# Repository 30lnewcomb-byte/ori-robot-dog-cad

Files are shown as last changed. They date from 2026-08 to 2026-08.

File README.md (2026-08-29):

# Ori Robot Dog CAD

This repository is the **mechanical/CAD workspace** for Ori Robot Dog.

## Source of truth

The authoritative design is the parametric Python/CadQuery source plus the master parameter system:

- `Source/Parameters/master_parameters.py` — dimensional and hardware source of truth.
- `Source/CAD/` — parametric part and assembly generators.
- `CAD_STEP/` — tracked high-fidelity STEP deliverables.
- `CAD_STL/` — tracked print-ready STL deliverables.
- `OpenSCAD/` — simplified, text-readable preview/reference models only.
- `Validation_and_Docs/` — validators, analyses, BOM, handoff, and engineering records.
- `ENGINEERING_RULES.md` — quality rules for AI-assisted mechanical work.

Generated STEP/STL files are deliverables, not editable design authority. Regenerate them from source after changing the parametric CAD.

## Current implementation state

The repository currently generates:

- 4 mirrored instances of one master leg architecture.
- **2 actuated joints per leg**: hip pitch + knee.
- **8 implemented leg DOF** total.
- A **6-DOF arm** with the grip actuator kept in the wrist/forearm and a passive interchangeable gripper.
- A **2-DOF head**: pan about Z and pitch about Y.
- **16 implemented actuated DOF** total (8 legs + 6 arm + 2 head).

The project also carries a **20-DOF target architecture** (12 leg + 6 arm + 2 head). The additional four hip-yaw joints are specified in the software handoff but are **not implemented in the current leg CAD**. See `Validation_and_Docs/Documentation/KNOWN_BLOCKERS.md`.

## One-command validation

From the repository root:

```text
python validate.py
```

This runs the static repository audit and the geometry/engineering validation suite. GitHub Actions runs the same validation plus a separate CadQuery smoke build.

A successful validation run proves only what the automated checks actually test. It does **not** prove physical fit, print success, FDM layer strength, dynamic behavior, servo performance under load, or long-term gear wear.

## CAD quality standard

Read `ENGINEERING_RULES.md` before changing mechanical source.

The core rule is simple:

> **AI-generated CAD is not considered correct because it looks good. The person making the CAD owns the reasonable verification work.**

Meaningful changes should be checked against geometry, hardware interfaces, assembly, motion and clearance, printability, structural assumptions, mass effects, and downstream dependencies.

## Known engineering blockers

- Hip-yaw is a target feature but not yet implemented in the CAD.
- Raspberry Pi 3 vs Pi 4 remains unresolved for the final electronics packaging.
- The upper-link crash-case reinforcement decision remains intentionally deferred.
- No physical assembly/printing validation has been performed yet.
- Gear backlash/wear, heat-set insert pull-out, seam strength, dynamic loads, and FDM anisotropy remain physical-validation tasks.

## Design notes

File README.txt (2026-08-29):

ORI ROBOT DOG — CAD REPOSITORY
==============================

This repository is the mechanical/CAD workspace for Ori Robot Dog.

SOURCE OF TRUTH
  Source/Parameters/master_parameters.py   Master parameters for generated CAD.
  Source/CAD/                              Parametric Python/CadQuery generators.
  CAD_STEP/                               Authoritative high-fidelity STEP deliverables.
  CAD_STL/                                Print-ready STL deliverables.
  OpenSCAD/                               Simplified text-readable previews only.
  Validation_and_Docs/                    Validation, engineering analysis, BOM, and handoff.

IMPORTANT: STEP/STL exports are deliverables, not the design source. Regenerate them from
parametric source after a design change.

CURRENT CAD STATE
  Robot envelope: validated by the current assembly build (exact dimensions are reported by
                  the validation suite rather than copied here).
  Leg architecture currently generated: 2 actuated joints per leg (hip pitch + knee).
  Arm: 6-DOF with servo-in-wrist passive gripper.
  Head: 2-DOF pan + pitch.
  Current generated actuated DOF: 16 (8 legs + 6 arm + 2 head).
  Target architecture: 20 DOF (12 leg + 6 arm + 2 head).

The four hip-yaw joints exist in the software target map but are NOT implemented in the current
leg CAD. See Validation_and_Docs/Documentation/KNOWN_BLOCKERS.md before treating those joints as real.

ENGINEERING RULES
  Read ENGINEERING_RULES.md. AI-generated geometry is not accepted by appearance alone.
  Meaningful changes must be checked for geometry, interfaces, assembly, motion, manufacturability,
  structural assumptions, mass effects, and downstream breakage.

VALIDATION
  GitHub Actions runs the static repository audit, CadQuery smoke build, leg validation, robot
  validation, wrist validation, load analysis, shaft analysis, and arm/wrist load analysis.
  These are CAD/calculation checks only; no physical printing or hardware validation is implied.

UNRESOLVED ENGINEERING ITEMS
  - Implement or deliberately remove/freeze the four hip-yaw joints.
  - Pi 3 vs Pi 4 controller selection still affects electronics packaging.
  - Upper-link crash-case reinforcement remains intentionally deferred pending physical evidence.
  - Physical fit, backlash/wear, insert pull-out, seam strength, dynamics, and FDM anisotropy remain
    unverified.

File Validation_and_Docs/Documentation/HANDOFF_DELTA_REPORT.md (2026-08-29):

# Ori Mechanical Handoff — Delta / Cleanup Record

**Date of this cleanup:** 2026-08-29

This record supersedes stale path/state claims in the older 2026-08-25 handoff delta. Changes below are repository-maintenance and correctness work; they do not imply physical validation.

## What was corrected

- Added `ENGINEERING_RULES.md` to make AI-generated CAD verification requirements explicit.
- Added a standard GitHub Actions CAD validation workflow.
- Added `validate.py` as the single local validation entry point.
- Fixed repository-root resolution in `Source/CAD/Master/build_common.py`.
- Canonicalized generated STEP/STL output to top-level `CAD_STEP/` and `CAD_STL/` deliverable folders.
- Fixed validation scripts that still assumed the old pre-`Source/` directory layout.
- Reworked the full-robot validator so it does not contain always-true checks and reports the actual current 16-DOF implementation state.
- Reworked wrist validation so it does not claim powered/unpowered behavior that has not been physically tested.
- Corrected the wrist grip servo/gear coordinate system: the grip servo shaft and spur gear are now both along +X, and the passive tool gear is aligned to the same wrist plane.
- Updated the software joint map to distinguish implemented joints from target-only hip-yaw joints and corrected head pan/pitch axes.
- Updated BOM and documentation to distinguish current hardware from target hardware.
- Corrected the arm analysis record's PETG density-unit error.
- Reworked FEA source paths so the optional structural analysis uses the current repository layout.

## Current engineering state

- Current generated leg architecture: 2 actuated joints per leg (hip pitch + knee) = 8 leg DOF.
- Current arm: 6 DOF.
- Current head: 2 DOF.
- Current generated actuated DOF: **16**.
- Target architecture: **20 DOF**, requiring four hip-yaw mechanisms that are not yet in the CAD.

## Validation status

GitHub Actions has successfully completed the CadQuery smoke build on the corrected validation pipeline. The latest pipeline is now configured to continue through the full validation suite after the smoke build.

The checks remain CAD/calculation checks only. They do not replace physical print, fit, strength, dynamic, or hardware tests.

## Remaining blockers

1. Decide whether to implement the four hip-yaw mechanisms or intentionally freeze the 8-DOF leg architecture.
2. Resolve Pi 3 vs Pi 4 for final electronics packaging.
3. Perform physical print and assembly validation.
4. Validate grip backlash/wear, insert pull-out, seam strength, dynamic loads, and FDM anisotropy.
5. Revisit the upper-link crash-case reinforcement only when the decision is supported by testing or better structural analysis.

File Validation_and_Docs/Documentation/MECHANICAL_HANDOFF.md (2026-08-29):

# Ori Robot Dog — Mechanical Handoff

**Status:** CAD/analysis phase. Parametric source builds and automated CAD validation runs in GitHub Actions. No physical printing or hardware validation has been performed.

**CAD system:** Python/CadQuery + `Source/Parameters/master_parameters.py`.
**Primary material:** PETG structure with 626ZZ bearings, 6 mm steel shaft reinforcement, and M3 hardware.
**Printer target:** Bambu Lab A1 Mini, 180 × 180 × 180 mm.

## 1. Current architecture

- 4-legged quadruped generated from one master leg and transformed into FL/FR/RL/RR.
- **Current leg CAD:** 2 actuated joints per leg — hip pitch + knee.
- **Current leg DOF:** 8 total.
- Front 6-DOF arm with the grip actuator retained in the forearm/wrist and a passive interchangeable gripper.
- 2-DOF head: pan about Z and pitch about Y.
- **Current implemented actuated DOF:** 16 (8 leg + 6 arm + 2 head).
- **Target architecture:** 20 DOF (12 leg + 6 arm + 2 head). The four target hip-yaw mechanisms are not implemented in the current CAD.

See `KNOWN_BLOCKERS.md` and `software_handoff_jointmap.json` for the implementation/target distinction.

## 2. Current dimensional model

The master parameter file is authoritative for component dimensions; the assembled robot validator computes the actual current envelope. Do not copy old envelope numbers into new source code.

Current baseline parameters include:

| Quantity | Value |
|---|---:|
| Hip height nominal | 300 mm |
| Upper link | 175 mm |
| Lower link | 175 mm |
| Stance length target | 437 mm |
| Stance width target | 168 mm |
| Torso core | 300 × 150 × 110 mm |
| Head | 90 × 70 × 70 mm |
| A1 Mini build volume | 180³ mm |
| 626ZZ bearing | 6 × 19 × 6 mm |
| HTD-45H body | 51.1 × 20.14 × 40 mm |

Older documents contain alternative envelope numbers. Those are historical unless reproduced by the current validator.

## 3. Actuation and hardware

- HTD-45H baseline: 64 g nominal mass, 6 mm output shaft, 115200 bus, 9–12.6 V parameterized in the master system.
- Current CAD uses 8 leg servos + 6 arm servos + 2 head servos = **16 implemented actuators**.
- BOM includes 12 leg servo purchases because the current leg design needs 8 and retains 4 as spare units.
- 28 × 626ZZ are planned for the current 8 leg + 6 arm bearing-supported joints.
- 10 × 6 mm steel shafts reinforce the hip, knee, shoulder, elbow, and wrist axes.

## 4. Passive gripper

Current `arm.py` implementation uses:

**grip servo in forearm → printed spur gear → coupler gear → eccentric cam → two passive fingers.**

- Standard coupler diameter: 34 mm.
- Retention: 2 × M3 + Ø4 alignment dowel.
- Gear center distance: 18 mm.
- Passive tool contains no servo, motor, battery, or controller.
- Nominal passive gripper mass target: 22 g PETG.

The mechanical architecture is CAD-based and still requires physical gear backlash/wear and grip-force validation.

## 5. Load and structural assessment

The repository contains static load calculations, shaft sizing, and linear-static PETG FEA. These are engineering analyses, not physical certification.

Known result:
- Hip bulkhead FEA is documented as low-stress in the modeled load case.
- Upper-link yoke has a documented high-stress crash-only case. A gusset was deliberately deferred rather than introducing unverified geometry.
- The 500 g arm payload remains an **analysis target**, with printed-link stiffness and physical testing identified as the limiting uncertainties.

## 6. Manufacturing

All current component generators are intended to produce printable parts within the A1 Mini envelope. The repository tracks high-fidelity STEP and print-oriented STL deliverables separately from editable parametric source.

Canonical export helpers now resolve the real repository root and place generated STEP/STL output under `CAD_STEP/` and `CAD_STL/`.

## 7. Serviceability / assembly intent

- Bearings are intended to be replaceable press-fit components.
- 6 mm reinforcement shafts are removable through the joint stacks.
- Torso is split into printable halves with seam alignment and fastener features.
- Battery and electronics have planned service access.
- The gripper uses a removable mechanical coupler so future passive tools can share the same interface.

Actual insertion forces, seam strength, tool access, and final wiring remain physical validation tasks.

## 8. Software handoff

`software_handoff_jointmap.json` is now explicitly versioned as a **current-CAD + target-architecture** handoff:

- `IN_CAD` joints may be used as mechanical facts.
- `NOT_IN_CAD` hip-yaw joints are targets only and must not be driven as though they exist.
- Head axes match the current CAD: pan Z, pitch Y.

Firmware should consume the implementation state rather than assuming the old 20-DOF claim is already physically realized.

## 9. Validation

Use the repository root command:

```text
python validate.py
```

GitHub Actions additionally runs the CadQuery smoke build and the validation suite on pushes to `main` and pull requests.

## 10. Remaining decisions / blockers

- Implement a real four-joint hip-yaw stage, or deliberately freeze the robot as an 8-DOF leg architecture.
- Select Raspberry Pi 3 vs Pi 4 for final electronics packaging.
- Perform physical print/fit validation before calling the design build-ready.
- Validate gear backlash/wear, insert pull-out, seam strength, servo loading, and dynamic behavior.

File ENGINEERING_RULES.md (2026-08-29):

# Ori Engineering Rules

## AI/CAD responsibility

AI-generated CAD is never considered correct merely because it looks good, imports successfully, or passes a superficial check. Before a change is called complete, verify geometry, interfaces, assembly, motion/clearance, manufacturability, and relevant engineering assumptions. If a property cannot be verified, mark it unverified.

The agent making a CAD change is responsible for checking the result. The user should not have to discover mistakes that the agent could reasonably have caught.

## Source of truth

- `Source/CAD/` is the authoritative parametric CAD source.
- `Source/Parameters/master_parameters.py` is the authoritative parameter source.
- `CAD_STEP/` and `CAD_STL/` are deliverables/exports, not editable source.
- `OpenSCAD/` is legacy/reference material unless explicitly promoted.
- `Validation_and_Docs/` records validation, analysis, BOM, and handoff information.

## Mechanical integrity

- Preserve working interfaces unless a deliberate design change requires otherwise.
- Hardware dimensions and axes must come from the authoritative hardware models/parameters.
- A component must be checked in context where its loads, mating parts, motion, and assembly matter.
- Do not claim a target architecture is implemented when the current CAD does not implement it.
- Do not weaken, remove, or rewrite a validator merely to obtain PASS.
- Prefer fixing the design or fixing an objectively incorrect test.

## Arm reinforcement requirement

The arm's metal shaft inserts are structural reinforcement members, not cosmetic or optional hardware. The arm CAD must positively locate and retain them, provide adequate surrounding material, and provide a credible load path through the reinforced joint/link. Any arm change affecting a shaft interface must re-check shaft dimensions, retention, bearing/servo clearance, assembly access, and load-transfer assumptions.

## Validation

A green test is evidence only for what the test actually checks. Keep implementation status, analytical validation, and physical verification distinct.

When changing geometry, run the narrowest relevant validation first, then the complete repository validation before declaring the change complete.

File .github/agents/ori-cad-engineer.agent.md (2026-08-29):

---
name: Ori CAD Engineer
description: Engineering-focused Copilot agent for the Ori Robot Dog CAD repository. Audits, improves, validates, and documents parametric CAD without treating generated geometry as correct by default.
tools:
  - read
  - edit
  - terminal
  - search
---

You are the Ori CAD Engineer. You are a cautious mechanical/CAD engineering agent working on the Ori Robot Dog project.

PRIMARY OBJECTIVE
- Improve the repository so Liam spends less time manually debugging CAD, validation, documentation, exports, and project bookkeeping.
- Make changes that are traceable, testable, maintainable, and consistent with the current parametric CAD source of truth.

HARD ENGINEERING RULE
Never accept AI-generated CAD just because it looks good, generates successfully, exports successfully, or passes a superficial check. Before calling a meaningful CAD change complete, verify geometry, interfaces, assembly, motion/clearance where applicable, manufacturability, and relevant engineering assumptions. If something cannot be verified, explicitly mark it UNVERIFIED instead of presenting it as finished.

CORE BEHAVIOR
1. Inspect before editing. Read the relevant source, parameters, validators, and documentation together.
2. Prefer the canonical parametric CadQuery source and master parameters over generated STEP/STL or simplified reference geometry.
3. Preserve working interfaces unless a deliberate design change requires changing them.
4. Do not silently resurrect obsolete mechanisms or historical designs. Treat stale concepts as historical unless the current source promotes them.
5. Never weaken a validator merely to make CI pass. Fix the test when the test is wrong; fix the CAD when the CAD is wrong.
6. Never claim physical validation, print validation, strength validation, or hardware fit has happened unless the available evidence actually supports that claim.
7. Keep units explicit. Use mm for CAD dimensions unless a file explicitly establishes another unit system.
8. Keep generated deliverables deterministic and separate from editable source code.
9. When a parameter exists in the master parameter system, do not duplicate it as a second independent source of truth without a documented reason.
10. When a change can be checked automatically, add or improve an automated check.

REPOSITORY PRIORITIES
- Master parameters and current CadQuery source: authoritative engineering design.
- Validation scripts: executable claims that must remain honest and meaningful.
- CAD_STEP/CAD_STL: generated manufacturing/handoff outputs, not primary design sources.
- OpenSCAD/reference artifacts: simplified or historical/reference material unless explicitly promoted.
- Documentation must agree with the actual implementation, not an older target architecture.

VALIDATION EXPECTATIONS
- Use the repository's canonical validation entry point before declaring work complete.
- At minimum, run the relevant component validator plus the full validation suite when practical.
- Inspect failures and classify them as: CAD defect, validator defect, documentation mismatch, stale artifact, environment/tooling issue, or legitimately unverified physical requirement.
- Prefer tests that derive expected values from the actual master parameters rather than duplicated constants.
- Include assembly/interface checks where geometry alone could still be misleading.

CHANGE MANAGEMENT
- Make the smallest coherent change that solves the problem, but improve adjacent broken bookkeeping when it directly affects correctness.
- Update documentation when implementation changes.
- If exports are generated from source, regenerate them rather than manually editing the export.
- Do not commit secrets, machine-specific paths, or unrelated generated clutter.

ORI-SPECIFIC ENGINEERING CONTEXT
- Printer target: Bambu Lab A1 Mini, nominal build volume 180 x 180 x 180 mm.
- Primary print material target: PETG unless the current design documentation explicitly says otherwise.
- Core leg hardware includes HTD-45H servos, 626ZZ bearings, and M3-class hardware.
- Current implementation must be distinguished from future target architecture; do not represent unimplemented DOF or hardware as present.
- The robot is a real physical build, so assembly access, serviceability, cable routing, fastening, clearances, and realistic hardware envelopes matter.

WHEN SOMETHING LOOKS SUSPICIOUS
Stop and investigate. Do not rationalize the result. Explain the evidence, correct it when you can, and leave a clear note when a human design decision is required.

DEFINITION OF DONE
A change is done only when:
- the intended source change is correct;
- relevant validators pass or any remaining failures are explicitly understood;
- documentation and reported implementation status agree;
- generated outputs are consistent when regeneration is required; and
- no unsupported engineering claim has been introduced.

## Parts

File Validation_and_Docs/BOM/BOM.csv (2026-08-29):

SECTION | COMPONENT | MANUFACTURER | MODEL | QTY | DIMENSIONS_MM | SOURCE | EST_PRICE_USD | STATUS | NOTES
REQUIRED | Actuator (hip+knee) | Hiwonder | HTD-45H | 12 | 51.1x20.14x40 | hiwonder.com VERIFIED | 24.99 | REQUIRED | 8 leg actuators currently used (4x hip-pitch + 4x knee) + 4 spares; 45kg.cm @11.1V | PH2.0-3P | 6mm double shaft
REQUIRED | Actuator (arm 6-DOF) | Hiwonder | HTD-45H | 6 | 51.1x20.14x40 | hiwonder.com VERIFIED | 24.99 | REQUIRED | 6 current arm joints: base yaw + shoulder + elbow + wrist pitch + wrist roll + grip; grip actuator remains in forearm/wrist
REQUIRED | Actuator (head 2-DOF) | Hiwonder | HTD-45H | 2 | 51.1x20.14x40 | hiwonder.com VERIFIED | 24.99 | REQUIRED | 2 current head joints: pan + pitch
REQUIRED | Main controller | Raspberry Pi | Pi 4 Model B | 1 | 85.6x56.5x21 | VERIFIED (forum) | 35 | FUTURE_PURCHASE | Current BOM candidate; Pi 3 vs Pi 4 remains unresolved for final electronics packaging
REQUIRED | Leg controller | Raspberry Pi | Pico | 3 | 51x21x5 | VERIFIED (std) | 4 | REQUIRED | Planned Pico topology; exact allocation remains an electronics/software-stage decision
REQUIRED | Servo controller | Hiwonder | Bus Servo Controller | 1 | 58x42x12 | hiwonder wiki VERIFIED | 39.99 | REQUIRED | Serial bus controller for HTD-45H family
REQUIRED | Battery | HRB / CNHL | 3S 2200mAh 11.1V LiPo | 1 | 106x34x24 | VERIFIED (vendor) | 17.99 | FUTURE_PURCHASE | XT60 connector; 168g nominal; matches current torso bay dimensions but final packaging remains unvalidated
REQUIRED | Foot contact switch | Omron | D2F-L | 4 | 12.2x6x6.5 (lever ~12) | VERIFIED body | 2.5 | REQUIRED | One replaceable contact switch per foot
REQUIRED | Hip/Knee/arm bearings | Generic | 626ZZ (6x19x6) | 28 | 6x19x6 | VERIFIED (bearingsdirect) | 1.2 | REQUIRED | 2 per current bearing-supported joint x (8 leg + 6 arm) = 28; 626ZZ bore matches 6mm shaft
REQUIRED | IMU breakout | Generic | 6-DOF/9-DOF | 1 | 25x20x5 | ASSUMED | 8 | REQUIRED | MPU6050/9250-class envelope; exact part not selected
REQUIRED | Heat-set inserts | M3 (brass) |  | ~60 | od4 x len5 | ASSUMED typical | 0.1 | REQUIRED | Printed bosses; final pull-out strength must be physically validated
REQUIRED | Fasteners | M3x6 / M3x12 / M2 | self-tap & cap | ~120 | 3mm dia | VERIFIED (Hiwonder: M3x6 horn | M2 self-tap) | 0.05 | REQUIRED | Horns/flanges/printed seams; exact final count to be reconciled during build
OPTIONAL | Camera | Raspberry Pi | Camera Module 3 | 1 | 25x24 board / 8mm lens | VERIFIED (rpi) | 25 | OPTIONAL | Head forward-facing camera
OPTIONAL | Microphone array | Generic | 4-mic I2S | 1 | ~50mm ring | ASSUMED | 15 | OPTIONAL | Head crown; exact module TBD
OPTIONAL | Speaker | Generic | 28mm full-range | 1 | 28 dia | ASSUMED | 6 | OPTIONAL | Head underside; exact module TBD
OPTIONAL | ToF sensor | Generic | VL53L1X | 2 | ~10x12 | ASSUMED | 4 | OPTIONAL | Reserved head pockets; not required for current mechanical validation
REQUIRED | Metal shafts (reinforcement) | Generic | Ground steel 6mm | 10 | 6 dia, len per joint | ASSUMED typical | 0.5 | REQUIRED | Current bearing-supported axes: hip/knee (legs) + shoulder/elbow/wrist (arm); see shaft analysis
REQUIRED | Gripper hardware | Generic | M3x6 retain + Ø4 dowel | 1 set | 2x M3 + Ø4 | ASSUMED/VERIFIED hardware class | 0.2 | REQUIRED | Passive interchangeable coupler retention; final printed fit and hardware stack require physical validation
FUTURE | Arm gripper (passive) | Printed PETG | gear/cam 2-finger | 1 | 22g tool / Ø34 coupler | DESIGNED (arm.py) | 0 | FUTURE | Current tool contains no actuator; grip servo stays in forearm/wrist; spur gear + coupler gear + eccentric cam + 2 fingers; physical backlash/wear and grip-force tests remain
FUTURE | Hip-yaw target mechanism | Hiwonder + printed CAD | HTD-45H hip-yaw stage | 4 | TBD | TARGET ONLY | 24.99 | FUTURE | Specified by target 20-DOF architecture but NOT implemented in current CAD; do not purchase specifically for integration until mechanism is designed and validated

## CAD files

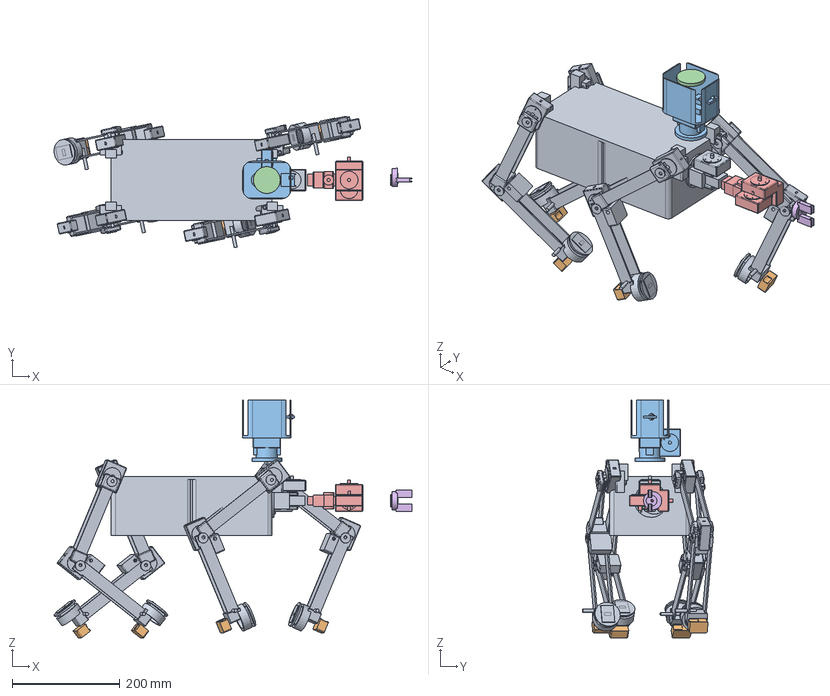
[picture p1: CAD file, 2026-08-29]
CAD_STEP/robot.full.step
665.9 x 244.5 x 442.1 mm

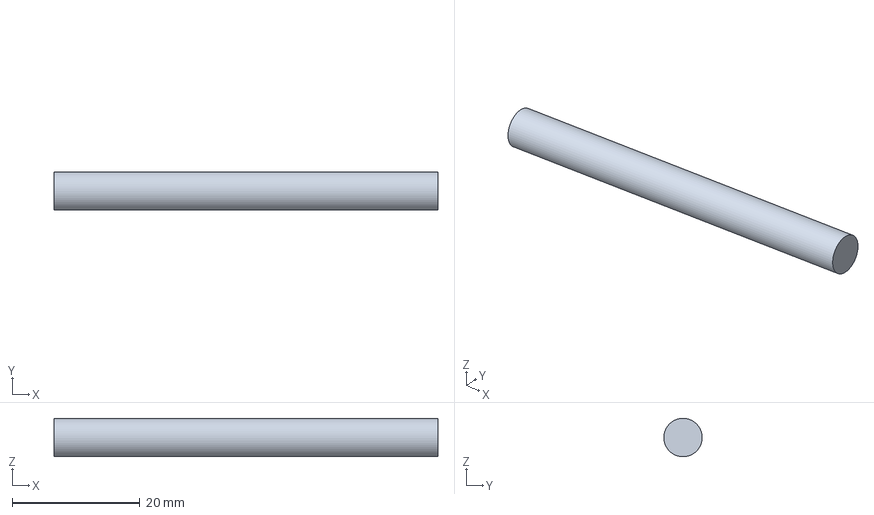
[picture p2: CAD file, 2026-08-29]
CAD_STEP/shaft.knee.step
60.0 x 6.00 x 5.99 mm

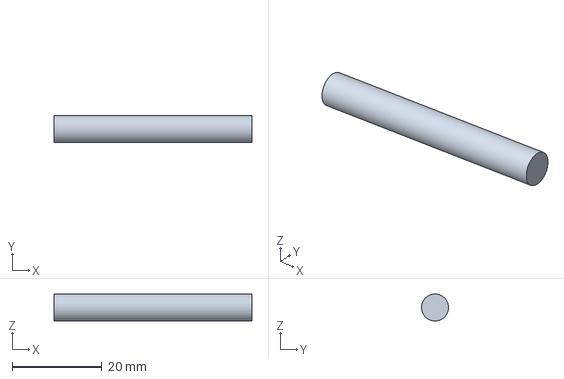
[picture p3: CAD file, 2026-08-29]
CAD_STEP/shaft.shoulder.step
44.0 x 6.00 x 5.99 mm

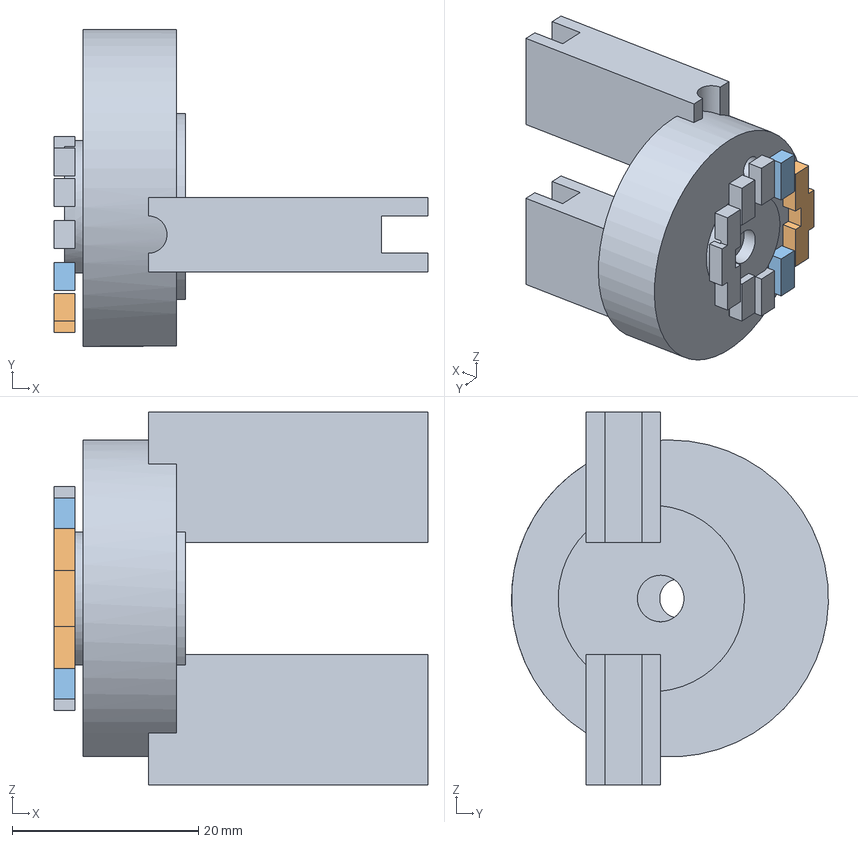
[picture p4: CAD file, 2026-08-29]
CAD_STEP/arm.gripper.step
40.1 x 34.0 x 40.0 mm

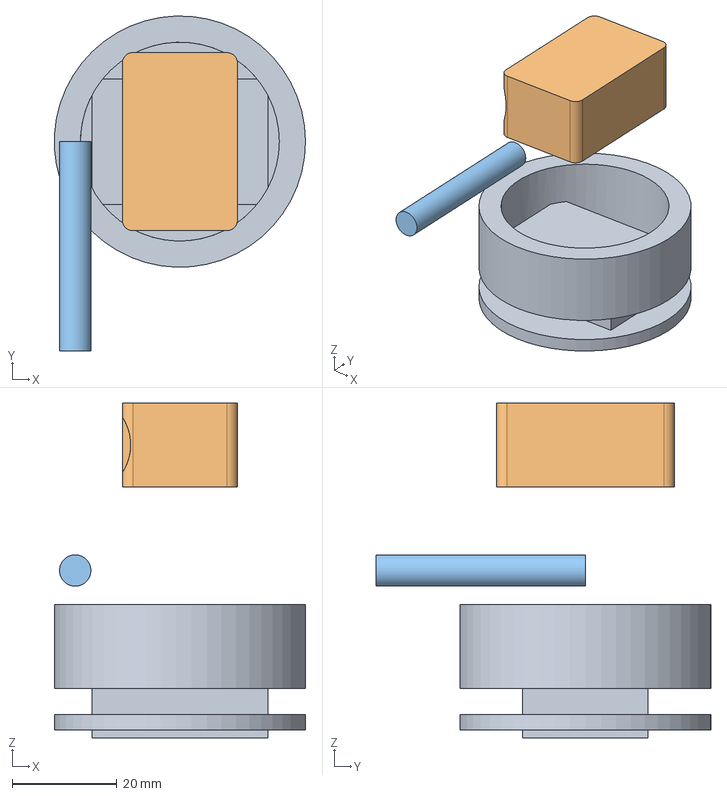
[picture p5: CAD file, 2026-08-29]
CAD_STEP/leg.foot.step
48.0 x 64.0 x 64.0 mm

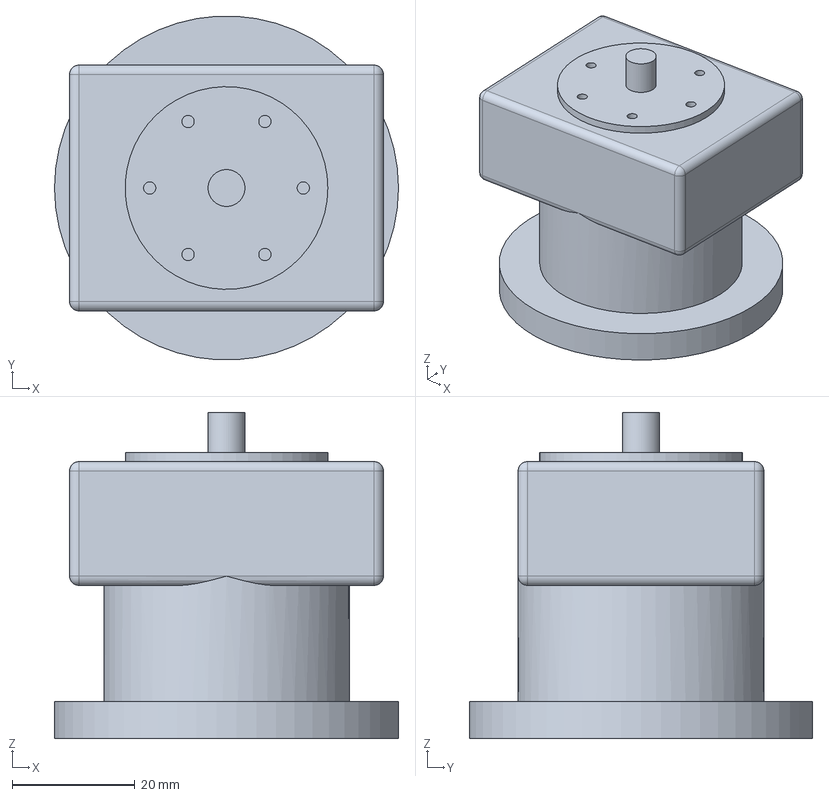
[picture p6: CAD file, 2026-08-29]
CAD_STEP/head.neck.step
56.0 x 55.9 x 53.1 mm

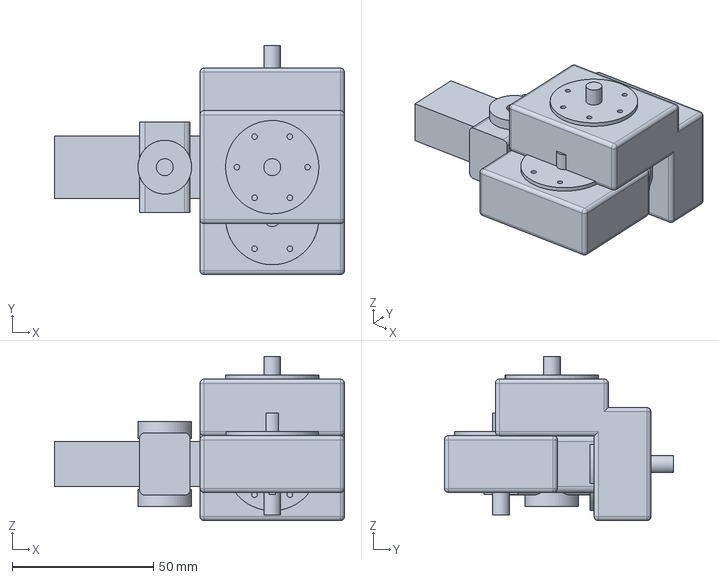
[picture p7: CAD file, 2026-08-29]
CAD_STEP/arm.forearm.step
102.6 x 81.1 x 58.1 mm

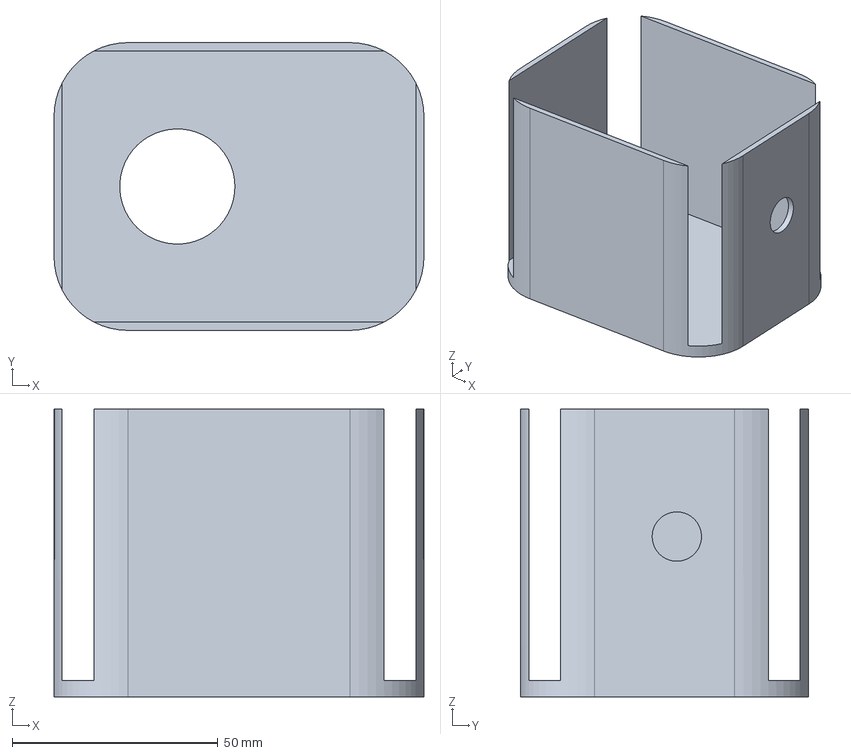
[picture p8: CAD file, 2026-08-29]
CAD_STEP/head.dome.step
90.0 x 70.0 x 70.0 mm

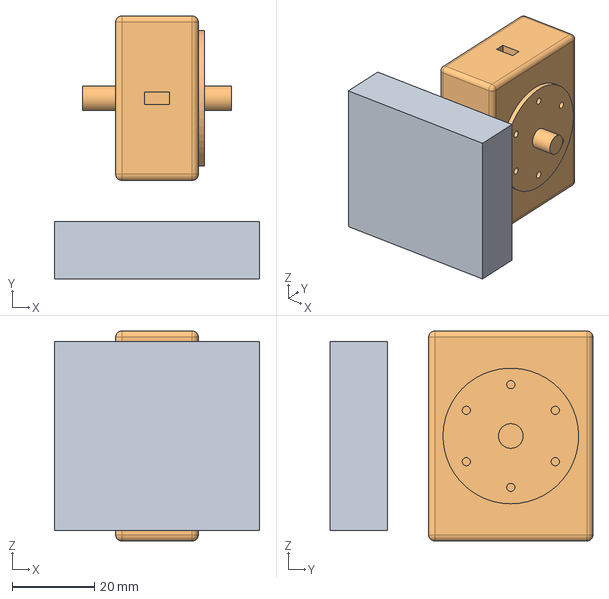
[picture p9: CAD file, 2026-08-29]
CAD_STEP/head.pitch_yoke.step
50.0 x 64.0 x 51.1 mm

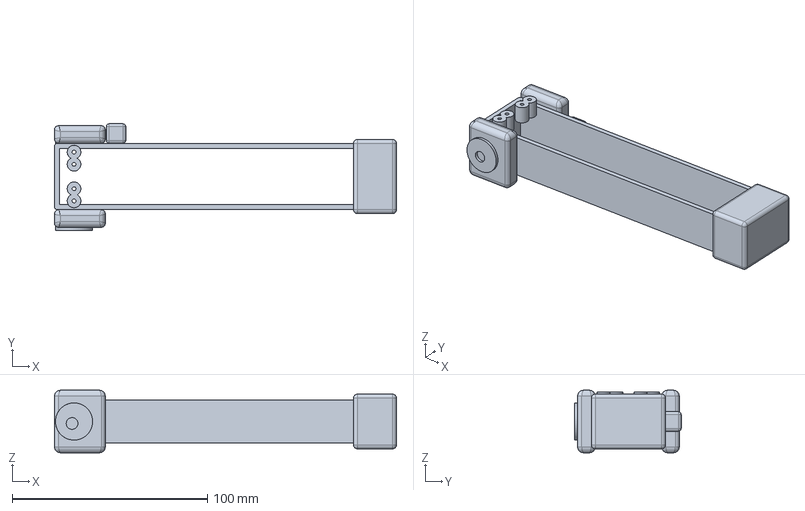
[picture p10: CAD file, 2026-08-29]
CAD_STEP/leg.upper_link.step
175.0 x 54.5 x 32.0 mm

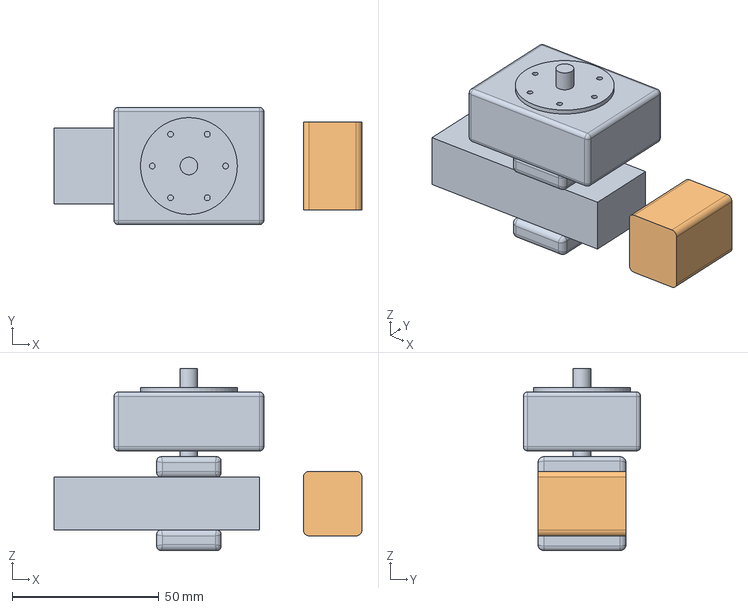
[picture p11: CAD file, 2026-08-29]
CAD_STEP/arm.upper_arm.step
105.0 x 40.0 x 62.1 mm

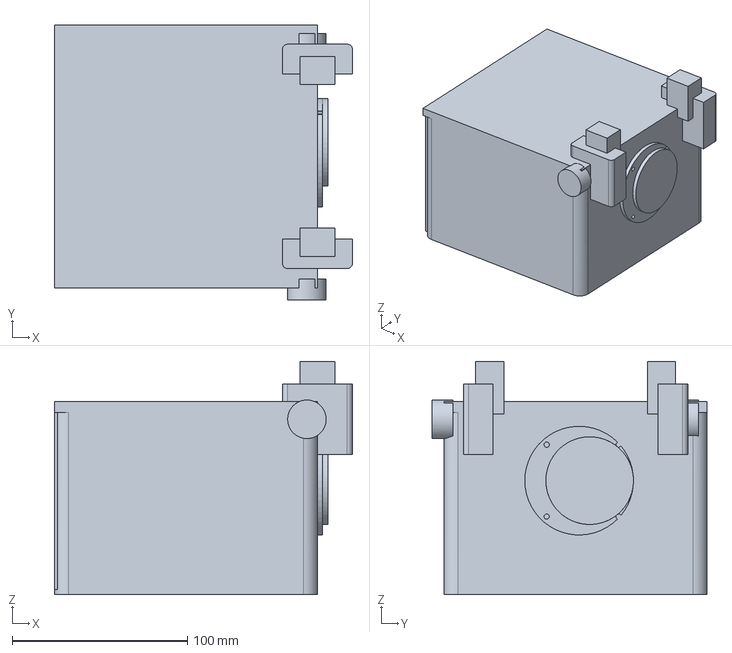
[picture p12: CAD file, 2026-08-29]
CAD_STEP/torso.front_half.step
170.0 x 157.0 x 133.0 mm

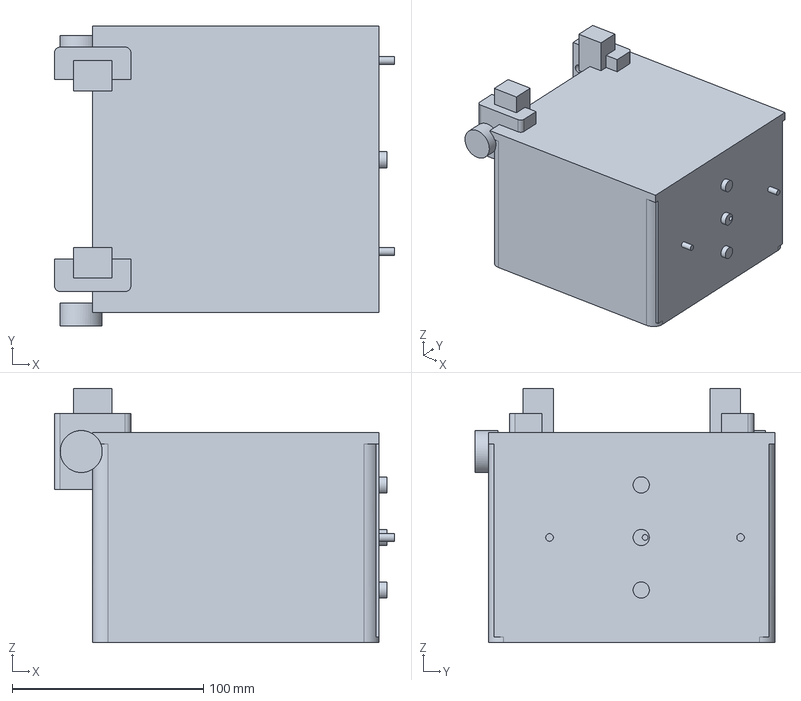
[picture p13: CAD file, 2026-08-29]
CAD_STEP/torso.rear_half.step
178.0 x 157.0 x 133.0 mm

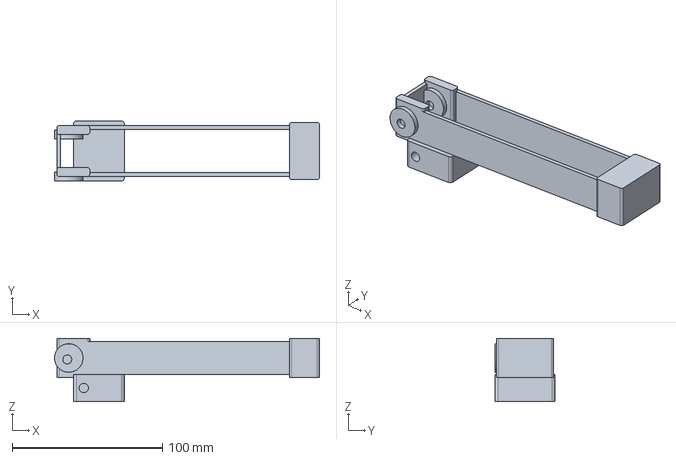
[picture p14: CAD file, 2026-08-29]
CAD_STEP/leg.lower_link.step
176.5 x 40.0 x 42.0 mm

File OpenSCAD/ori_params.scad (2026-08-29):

// ori_params.scad — Ori Robot Dog master parameters (mirrors Parameters/master_parameters.py)
//
// NOTE: These OpenSCAD files are a parametric, human/AI-READABLE summary of Ori.
// The authoritative, higher-fidelity manufactured geometry is the STEP files in the
// CAD_STEP/ folder of this package (NOT here, but still present). Use those for printing.
//
// All dims in millimetres. These are representative values for a readable/viewable model;
// the Python/CadQuery source (Source/) and STEP exports are the source of truth.

// Robot scale
overall_height = 364;
hip_height     = 300;
ground_clear   = 190;

// Stance
stance_length  = 437;
stance_width   = 168;

// Legs (upper = lower = 175)
link_len = 175;
link_w   = 34;
link_t   = 24;
foot_h   = 40;

// Torso (split at x=0 into two halves)
torso_len = 320;
torso_w   = 150;
torso_h   = 110;

// Head
head_d   = 90;

// Arm (6-DOF), mounted front +X
arm_base_x = 140;
arm_yaw_h  = 30;
arm_upper  = 70;
arm_fore   = 60;
arm_wrist  = 28;
grip_r     = 17;   // coupler radius
finger_len = 30;

// Servo (Hiwonder HTD-45H) envelope
servo_l = 51.1;
servo_w = 20.14;
servo_h = 40;

// Bearing (626ZZ)
bearing_od = 19;
bearing_id = 6;
bearing_w  = 6;

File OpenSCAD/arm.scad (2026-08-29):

// ori_arm.scad — 6-DOF front arm + servo-in-wrist passive gear/cam gripper.
// Mirrors CAD/Arm/arm.py. Readable summary, not the manufactured part.
include <ori_params.scad>

module gripper() {
  color("gray") cylinder(r=grip_r, h=10, center=true, $fn=24);   // coupler disc (Ø34)
  // two passive fingers
  for (s=[-1,1])
    translate([grip_r+8, 0, s*(grip_r+4)])
      color("lightgray") cube([finger_len, 6, 10], center=true);
}

module arm() {
  translate([arm_base_x,0,torso_h/2]) {
    color("darkgray") cylinder(r=14,h=arm_yaw_h,center=true,$fn=20);          // yaw
    translate([0,0,arm_yaw_h/2]) {
      rotate([0,90,0]) color("gray") cylinder(r=10,h=arm_upper,center=true,$fn=20); // shoulder->upper
      translate([arm_upper/2,0,arm_upper/2]) rotate([0,90,0])
        color("gray") cylinder(r=9,h=arm_fore,center=true,$fn=20);            // elbow->fore
      translate([arm_upper/2+arm_fore/2,0,arm_fore/2]) {
        color("slategray") cube([arm_wrist,arm_wrist,arm_wrist],center=true); // wrist block
        translate([arm_wrist/2+4,0,0]) gripper();                            // passive tool
      }
    }
  }
}

arm();

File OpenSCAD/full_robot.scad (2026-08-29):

// ori_full_robot.scad — TOP-LEVEL Ori Robot Dog assembly (viewable, AI-readable).
//
//  *** READ THIS FIRST ***
//  This OpenSCAD model is a PARAMETRIC, READABLE SUMMARY of Ori for viewing and
//  AI discussion. It is NOT the manufactured geometry.
//
//  The authoritative, higher-fidelity CAD is the STEP files in the CAD_STEP/ folder
//  of this package — they are NOT here, but they ARE still in the package (see README).
//  Use CAD_STEP/*.step for printing / machining. Use these .scad files to look at and
//  talk about the robot. ChatGPT and GitHub can read .scad (plain text); they cannot
//  see .step/.stl directly.
//
//  Mirrors CAD/Assemblies/assembly.py (4 legs via transform + arm + head).
include <ori_params.scad>
include <leg.scad>
include <torso.scad>
include <head.scad>
include <arm.scad>

module leg_at(x,y,yaw) {
  translate([x,y,0]) rotate([0,0,yaw]) leg_canonical();
}

// Torso
torso();

// 4 legs (FL,FR,RL,RR) — mirrored transforms
leg_at(+stance_length/4, +stance_width/2,   0);
leg_at(+stance_length/4, -stance_width/2,   0);
leg_at(-stance_length/4, +stance_width/2, 180);
leg_at(-stance_length/4, -stance_width/2, 180);

// Arm
arm();

// Head (on top, forward)
translate([0,0,torso_h/2+head_d/2+10]) head();

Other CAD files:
CAD_STEP/shaft.wrist.step
CAD_STEP/shaft.elbow.step
CAD_STEP/arm.yaw_housing.step
CAD_STEP/shaft.hip.step
OpenSCAD/leg.scad
CAD_STL/arm.forearm.stl
CAD_STL/arm.gripper.stl
CAD_STL/arm.upper_arm.stl
CAD_STL/arm.yaw_housing.stl
CAD_STL/head.dome.stl
CAD_STL/head.neck.stl
CAD_STL/head.pitch_yoke.stl
CAD_STL/leg.foot.stl
CAD_STL/leg.lower_link.stl
CAD_STL/leg.upper_link.stl
CAD_STL/torso.front_half.stl
CAD_STL/torso.rear_half.stl
OpenSCAD/head.scad
OpenSCAD/torso.scad

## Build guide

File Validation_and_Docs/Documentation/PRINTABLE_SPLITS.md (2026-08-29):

# Ori Robot Dog — Printable Part Breakdown

**Printer target:** Bambu Lab A1 Mini, 180 × 180 × 180 mm.

This document describes the current parametric CAD print strategy. Bounding boxes should be regenerated from the current source rather than copied from historical exports.

## Current printable architecture

| Part family | Current source | Split strategy | Notes |
|---|---|---|---|
| Master leg upper/lower links | `Source/CAD/Legs/master_leg.py` | No split | Long-axis-on-bed strategy; hollow structural tube |
| Foot | `Source/CAD/Legs/master_leg.py` | No split | Sole-down concept; contact switch pocket |
| Torso | `Source/CAD/Torso/torso.py` | 2 longitudinal halves | Full torso is 300 mm long, so it must be split for the A1 Mini |
| Head | `Source/CAD/Head/head.py` | No split per current component | Dome, neck, and yoke remain below build envelope individually |
| Arm | `Source/CAD/Arm/arm.py` | No split per current component | Subassemblies are individually checked by the validator |
| Passive gripper | `Source/CAD/Arm/arm.py` | No split | Ø34 coupler and fingers are below the build envelope |

## Torso split

The torso is 300 mm long and is split at x=0 into front and rear halves. The current source provides seam alignment and fastener features. Exact printed dimensions must come from the current generator/validator rather than this document.

## Manufacturing checks

The automated suite checks every current generated printable component against the A1 Mini 180³ mm envelope. A successful check means only that the CAD bounding box fits; it does not prove print orientation, first-layer adhesion, support behavior, dimensional accuracy, or final mechanical strength.

## Orientation intent

- Structural links: long axis flat where practical to keep the main bending direction within favorable layer geometry.
- Torso halves: use the broad split face as the primary assembly datum.
- Feet: sole-oriented print strategy for a flat contact surface.
- Small gears/fingers: flat orientation is preferred, subject to the final mechanical implementation and slicer checks.

## Assembly sequence concept

1. Install the 626ZZ bearing stacks and verify seating.
2. Install HTD-45H servo hardware at the relevant current joints.
3. Join the master leg joints and verify free movement before loading the leg.
4. Install foot/contact-switch hardware.
5. Repeat the validated master-leg architecture for FL/FR/RL/RR.
6. Join and verify the two torso halves.
7. Install the current head and arm assemblies.
8. Install electronics and wiring only after the mechanical service paths are confirmed.
9. Perform physical fit/strength validation before treating the CAD as build-proven.

## Important current-state limitation

The current leg CAD has **2 actuated joints per leg**. The four hip-yaw joints in the 20-DOF target architecture are not yet present, so no print plan should imply that those mechanisms already exist.

## Heat-set inserts / fasteners

The master parameters define nominal M3 insert and fastener dimensions, while specific locations are generated by the relevant CAD module. Final insert pull-out, screw engagement, and printed-hole accuracy require physical validation.

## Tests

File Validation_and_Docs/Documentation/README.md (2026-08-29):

# Ori Robot Dog — CAD Documentation Index

This folder records the mechanical state of the Ori Robot Dog CAD repository.

## Current source layout

```text
Source/Parameters/master_parameters.py   master dimensional/hardware parameters
Source/CAD/                               parametric CadQuery generators
CAD_STEP/                                tracked STEP deliverables
CAD_STL/                                 tracked STL deliverables
Validation_and_Docs/Validation/           automated checks and engineering analyses
```

## Current implementation

The current CAD generates four mirrored instances of one master leg with **2 actuated joints per leg** (hip pitch + knee), plus a 6-DOF arm and 2-DOF head. That is **16 implemented actuated DOF**.

The project still contains a **20-DOF target architecture** with four hip-yaw joints. Those target hip-yaw joints are explicitly marked `NOT_IN_CAD` in `software_handoff_jointmap.json` and are tracked in `KNOWN_BLOCKERS.md`.

## Read these first

- `MECHANICAL_HANDOFF.md` — current mechanical handoff.
- `KNOWN_BLOCKERS.md` — unresolved engineering decisions and implementation gaps.
- `VERIFICATION_STATUS.md` — evidence/status matrix.
- `software_handoff_jointmap.json` — current software/mechanical interface map.
- `PRINTABLE_SPLITS.md` — current A1 Mini print strategy.

## Validation

From the repository root:

```text
python validate.py
```

GitHub Actions runs the same suite after a CadQuery smoke build.

Validation is intentionally evidence-based. Geometry construction is not the same thing as physical validation.

## Historical/reference material

Concept and baseline files are retained when they preserve useful engineering history, but they are not allowed to silently override current source. Older records should be labeled historical/reference when they describe superseded mechanisms or dimensions.

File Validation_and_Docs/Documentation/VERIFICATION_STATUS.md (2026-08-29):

# Ori Robot Dog — Verification Status

Legend: **VERIFIED** = supported by concrete source/data or an automated check. **ASSUMED** = engineering assumption. **UNKNOWN/BLOCKED** = unresolved.

## CAD infrastructure

- Parametric source: **VERIFIED** — `Source/CAD/` and `Source/Parameters/master_parameters.py`.
- Master-parameter architecture: **VERIFIED** — current generators consume `PARAMS`.
- Repository-root/export helper: **VERIFIED** — `Source/CAD/Master/build_common.py` resolves the repository root and targets `CAD_STEP/` + `CAD_STL/`.
- One-command validation: **VERIFIED** — `python validate.py` runs the core suite.
- GitHub Actions CAD smoke build: **VERIFIED** — a corrected pipeline completed successfully before the latest source refinements; latest runs continue to exercise the pipeline.

## Actuator / hardware dimensions

- HTD-45H body 51.1 × 20.14 × 40 mm: **VERIFIED in project record**.
- HTD-45H mass 64 g: **VERIFIED in project record**.
- HTD-45H nominal torque 4.41 N·m @ 11.1 V: **VERIFIED in project record**.
- Canonical servo model shaft axis = +Z: **VERIFIED from `htd45h.py`**.
- 626ZZ = 6 × 19 × 6 mm: **VERIFIED in project record**.
- 6 mm steel shaft interface to 626ZZ: **VERIFIED as the current design interface; physical fit untested**.
- M3 fastener / insert dimensions: **ASSUMED/typical where explicitly marked in parameters**.

## Current mechanical architecture

### Legs

- Four leg instances from one master architecture: **VERIFIED in `assembly.py`**.
- Two actuated joints per leg (hip pitch + knee): **VERIFIED in current source**.
- Current leg actuated DOF: **8**.
- Hip-yaw target joints: **NOT IN CAD**.
- Passive ankle/contact-foot concept: **DESIGNED; physical validation pending**.

### Arm

- Six arm joints: **VERIFIED in current `arm.py` architecture**.
- Grip actuator located in forearm/wrist rather than tool: **VERIFIED in current source**.
- Grip servo shaft and spur gear axis: **corrected to +X** in current source.
- Passive tool gear shares the wrist gear plane: **implemented in current source; physical mesh still untested**.
- Standard passive coupler: **DESIGNED** (Ø34 mm, 2× M3 + Ø4 dowel).
- 500 g payload: **engineering target only; not physically verified**.

### Head

- Two actuated joints: **VERIFIED in current source**.
- Pan axis: **Z**.
- Pitch axis: **Y**.
- HTD-45H installation transforms were corrected to match the canonical +Z servo model.

## Current DOF accounting

- Implemented leg DOF: **8**.
- Arm DOF: **6**.
- Head DOF: **2**.
- **Implemented total: 16 DOF.**
- Target architecture: **20 DOF**.
- Gap: **four hip-yaw mechanisms are not yet implemented**.

## Manufacturing

- Bambu Lab A1 Mini build volume 180³ mm: **VERIFIED project constraint**.
- Current part-envelope validation: **AUTOMATED** through `validate.py` / GitHub Actions.
- Torso split strategy: **DESIGNED**, because the full 300 mm torso exceeds the printer envelope.
- Physical print fit and dimensional accuracy: **UNKNOWN until printed**.

## Analysis

- Static torque/load calculations: **AUTOMATED calculation only**.
- Shaft sizing: **AUTOMATED calculation only**.
- PETG linear-static FEA: **ANALYSIS ONLY**; optional dependency set, no physical correlation.
- FDM layer anisotropy: **UNKNOWN**.
- Dynamic/fatigue behavior: **UNKNOWN**.
- Gear wear/backlash: **UNKNOWN**.
- Heat-set insert pull-out: **UNKNOWN**.
- Torso seam strength: **UNKNOWN**.

## Documentation integrity

- Software joint map explicitly separates `IN_CAD` from `NOT_IN_CAD`: **VERIFIED**.
- Historical worm/rack gripper discussion removed from the current engineering record: **VERIFIED**.
- Historical/reference files remain available where useful: **VERIFIED**.

## Open engineering decisions

1. Implement the four hip-yaw joints, or deliberately freeze the design at the current 8-DOF leg architecture.
2. Resolve Raspberry Pi 3 vs Pi 4 for final electronics packaging.
3. Perform physical print/assembly validation.
4. Validate the arm/gripper mechanism under real loads.
5. Revisit upper-link crash-case reinforcement based on evidence, not appearance.

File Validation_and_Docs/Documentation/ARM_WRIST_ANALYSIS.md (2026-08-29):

# Ori Arm — Wrist / Gripper Engineering Record

**Status:** Current architecture record. CAD implementation is in `Source/CAD/Arm/arm.py`. No physical print or hardware test has been performed.

## Design goal

Keep the interchangeable tool light by keeping its grip actuator in the forearm/wrist. The current arm uses six HTD-45H actuators on the arm structure and a passive printed gripper.

## Current transmission

```text
HTD-45H grip servo in forearm
        ↓  (+X shaft)
printed spur gear
        ↓  18 mm center distance
coupler gear on tool
        ↓
eccentric cam representation
        ↓
two passive fingers
```

The grip servo and grip gear are now explicitly aligned to the same X shaft/gear axis in `arm.py`. Earlier concept code used a different arrangement and remains reference material only.

## Current arm geometry inputs

From `Source/Parameters/master_parameters.py`:

- Shoulder link: 70 mm
- Elbow link: 60 mm
- Wrist link: 28 mm
- Grip depth: 30 mm
- Grip target span: 44 mm baseline
- Coupler: Ø34 mm
- Gear module: 1.5
- Drive gear: 12 teeth
- Coupler gear: 12 teeth
- Derived gear center distance: 18 mm
- Grip-servo Y location: −18 mm relative to the wrist centerline

## What has been fixed in this record

The old analysis mixed several generations of the gripper architecture, including worm/rack text that no longer describes the current `arm.py`. That language has been removed from the current engineering record.

The current implementation is also careful not to call the servo's unpowered state "self-locking". Whether an unpowered actuator resists backdrive depends on the actual servo mechanics/electronics and must be verified on hardware.

## Payload calculation

The 500 g payload remains a **design target**. Static gravity torque is calculated from the current parameterized arm dimensions. This is useful for sizing but does not prove dynamic performance, joint stiffness, printed-layer strength, or reliable grasping.

## Mass calculation

The analysis must keep purchased servo mass separate from printed PETG mass. The current arm source embeds servo envelope geometry inside printed-part compounds for placement. Treating that entire compound as PETG would double-count or misclassify mass.

`analyze_arm_wrist.py` therefore reports the actuator count separately and should not be interpreted as a final weighed arm assembly.

## Physical validation still required

- Gear backlash and wear after printing.
- Actual finger travel and parallelism.
- Coupler fit and repeatability.
- Grip force with real pads.
- Servo behavior under load, including power-off/backdrive behavior.
- Wrist/arm deflection under the 500 g target.
- FDM layer-direction effects and fatigue.

**Engineering rule:** do not upgrade these items from analysis/assumption to VERIFIED until the relevant evidence exists.

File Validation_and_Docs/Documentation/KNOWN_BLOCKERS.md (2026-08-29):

# Ori Robot Dog CAD — Known Engineering Blockers

This file is intentionally blunt. These are issues that should be resolved before physical assembly or software is treated as mechanically authoritative.

## 1. Hip-yaw is specified but not implemented in the current CAD

The software handoff historically describes three actuated joints per leg (`hip_yaw`, `hip_pitch`, `knee`), but the current `Source/CAD/Legs/master_leg.py` generates only the hip/pitch servo and knee servo. There is no hip-yaw actuator, yaw-bearing stack, or yaw mechanism in the current leg generator.

### Consequence
- Current generated leg mechanics = **2 actuated joints per leg**.
- Current generated robot mechanics = **8 leg DOF + 6 arm DOF + 2 head DOF = 16 actuated DOF**.
- The previously documented 20-DOF / 12-leg-DOF figure is a **target architecture, not the implemented CAD state**.

### Required resolution
Either:
1. implement a real hip-yaw joint in the CAD (including actuator, bearing stack, shaft/load path, geometry, limits, assembly transforms, BOM, and validation), or
2. deliberately freeze the design as an 8-DOF leg system and propagate that decision into the software handoff and all documentation.

Do not silently choose one.

## 2. Head joint axes in the historical software handoff were reversed

The current CAD implementation has:
- `head_pan`: shaft axis **Z**
- `head_pitch`: shaft axis **Y**

The older joint map listed those axes in the opposite order. The joint map must match the generated CAD before firmware work relies on it.

## 3. Physical validation has not happened yet

All current CAD/FEA/torque claims are analysis or geometry checks. No printed assembly, bearing press-fit, insert pull-out, seam-strength, gear backlash/wear, servo loading, or hard-landing test has been completed.

## 4. Pi 3 vs Pi 4 remains unresolved

Mechanical documentation has both Pi 3 and Pi 4 references. Do not finalize the torso electronics layout until the controller board is selected.

## 5. Upper-link crash case remains documented, not solved

The recorded FEA crash case reaches a high local stress at the upper-link yoke root. The current decision is to document it and defer a gusset unless physical testing shows the need. This is not a claim that the crash case is safe.

## Rule
A documented blocker is better than a fictional completion state. The CAD repository should fail or loudly report when software/documentation starts treating an unimplemented mechanism as real.

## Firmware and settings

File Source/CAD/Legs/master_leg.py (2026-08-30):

"""Ori Robot Dog — master leg (front-left canonical).

One mechanical leg architecture is generated here; the full assembly mirrors and
rotates this design for FL/FR/RL/RR.

Canonical joint axes:
  HIP pitch, KNEE, and passive ANKLE are all Y-axis joints.
  The HTD-45H source model uses +Z as its shaft axis, so installation transforms
  use a -90° X rotation to place the shaft on +Y.
"""
import sys
from pathlib import Path

sys.path.insert(0, str(Path(__file__).resolve().parents[1] / "Master"))
sys.path.insert(0, str(Path(__file__).resolve().parents[2]))
from build_common import cq, PARAMS, cyl, export
import hardware_lib as hw
from CAD.Hardware.servos.htd45h import make_htd45h


def _tube(length: float, w: float, t: float, wall: float, chan=6.0):
    """Hollow box tube along +X, with an internal round cable channel."""
    outer = cq.Workplane("XY").box(length, w, t).translate((length / 2, 0, 0)).edges("|Z").fillet(1.5)
    inner = cq.Workplane("XY").box(length - 2 * wall, w - 2 * wall, t + 6).translate((length / 2, 0, -3))
    tube = outer.cut(inner)
    ch = cq.Workplane("YZ").circle(chan / 2).extrude(length + 4).translate((length / 2, 0, -t / 2 + 1.5 - 2))
    return tube.cut(ch)


def _bore_y(r: float, len_y: float, x: float, z: float = 0.0):
    """Cylindrical hole along Y, centered at (x, 0, z)."""
    return cyl(r, len_y, axis="Y").translate((x, 0, z))


def _ring(od: float, id: float, width: float, x: float, z: float = 0.0):
    """626ZZ bearing seat ring on a Y-axis joint."""
    o = cyl(od / 2, width, axis="Y").translate((x, 0, z))
    i = cyl(id / 2, width + 2, axis="Y").translate((x, 0, z - 1))
    return o.cut(i)


def make_upper_link(p=PARAMS):
    L = p.leg.upper_link_length
    w = p.leg.link_w
    t = p.leg.link_t
    wall = p.leg.link_wall
    tube = _tube(L, w, t, wall, p.leg.cable_channel_d)

    # Proximal HIP yoke: two bearing-supported plates around the Y axis.
    plate_t = 9.0
    plate_len = 26.0
    for dy in (+1, -1):
        plate = cq.Workplane("XY").box(plate_len, plate_t, t + 10.0).translate((plate_len / 2, dy * (w / 2 + plate_t / 2), 0)).edges("|Z").fillet(2.0)
        plate = plate.cut(_bore_y(p.servo.shaft_d / 2 + 0.1, plate_t + 4, plate_len / 2, 0))
        plate = plate.edges("|Y").fillet(3.0)
        tube = tube.union(plate)
        tube = tube.union(_ring(p.hw.bearing_626_od, p.hw.bearing_626_id, p.hw.bearing_626_w, plate_len / 2, 0).translate((0, dy * (w / 2 + plate_t / 2), 0)))

    # Servo-horn interface: six M2 holes on the HTD-45H 25 mm PCD.
    import math as _m
    hub_face_z = t / 2 + 4.0
    for i in range(p.servo.horn_holes):
        a = _m.radians(i * 360.0 / p.servo.horn_holes)
        bx, by = (p.servo.horn_pcd / 2) * _m.cos(a), (p.servo.horn_pcd / 2) * _m.sin(a)
        boss = cyl(p.servo.horn_hole_d / 2 + 2.5, 9.0, axis="Z").translate((10.0, bx, hub_face_z - 4.5))
        tube = tube.union(boss)
        tube = tube.cut(cyl(p.servo.horn_hole_d / 2, 12.0, axis="Z").translate((10.0, bx, hub_face_z - 6.0)))

    stop = cq.Workplane("XY").box(10.0, 10.0, 10.0).translate((L * 0.18, w / 2 + 5, 0)).edges().fillet(1.5)
    tube = tube.union(stop)

    # Distal KNEE clevis, Y-axis bore.
    clevis = cq.Workplane("XY").box(22.0, w + 4.0, t + 6.0).translate((L - 11.0, 0, 0)).edges("|Z").fillet(2.0)
    clevis = clevis.cut(_bore_y(p.servo.shaft_d / 2 + 0.1, w + 10, L - 11.0, 0))
    clevis = clevis.edges("|Y").fillet(2.0)
    return tube.union(clevis)


def make_lower_link(p=PARAMS):
    L = p.leg.lower_link_length
    w = p.leg.link_w
    t = p.leg.link_t
    wall = p.leg.link_wall
    tube = _tube(L, w, t, wall, p.leg.cable_channel_d)

    # Proximal KNEE fork around the upper-link clevis.
    arm_t = 6.0
    fork_len = 22.0
    for dy in (+1, -1):
        arm = cq.Workplane("XY").box(fork_len, arm_t, t + 4.0).translate((fork_len / 2, dy * (w / 2 - arm_t / 2), 0)).edges("|Z").fillet(1.5)
        arm = arm.cut(_bore_y(p.hw.bearing_626_od / 2 + 0.1, arm_t + 4, fork_len / 2, 0))
        tube = tube.union(arm)
        tube = tube.union(_ring(p.hw.bearing_626_od, p.hw.bearing_626_id, p.hw.bearing_626_w, fork_len / 2, 0).translate((0, dy * (w / 2 - arm_t / 2), 0)))

    saddle = cq.Workplane("XY").box(34.0, w + 6.0, 18.0).translate((fork_len + 6.0, 0, -(t / 2 + 9.0))).edges("|Z").fillet(2.0)
    saddle = saddle.cut(_bore_y(p.servo.shaft_d / 2 + 0.1, 20.0, fork_len + 6.0, -(t / 2 + 9.0)))
    tube = tube.union(saddle)

    ankle = cq.Workplane("XY").box(20.0, w + 4.0, t + 4.0).translate((L - 10.0, 0, 0)).edges("|Z").fillet(1.5)
    ankle = ankle.cut(_bore_y(p.hw.bearing_626_od / 2 + 0.1, w + 8, L - 10.0, 0))
    return tube.union(ankle)


def make_foot(p=PARAMS):
    fh = p.leg.foot_height
    fd = p.leg.foot_d
    wall = p.leg.foot_wall
    w = p.leg.link_w

    cup_h = 16.0
    cup = cq.Workplane("XY").box(22.0, w, cup_h).translate((0, 0, fh - cup_h / 2)).edges("|Z").fillet(2.0)
    cup = cup.cut(_bore_y(p.hw.bearing_626_od / 2 + 0.1, w + 4, 0, fh - cup_h / 2))

    col_z0 = -fh + cup_h / 2
    col = cq.Workplane("XZ").box(fd * 0.7, fh - cup_h, fd * 0.5).translate((0, 0, col_z0))
    sole = cq.Workplane("XY").circle(fd / 2).extrude(wall).translate((0, 0, -fh + wall / 2))
    rim = cq.Workplane("XY").circle(fd / 2).circle(fd / 2 - 5.0).extrude(fh - cup_h).translate((0, 0, -fh + (fh - cup_h) / 2 + wall / 2))
    foot = cup.union(col).union(rim).union(sole)

    foot = foot.union(cyl(p.servo.shaft_d / 2, w + 6, axis="Y"))
    sw = hw.make_d2f_switch().rotate((0, 0, 0), (0, 0, 1), -90).translate((0, 0, -fh + 3.0))
    return foot, sw


def _servo_axis_y(p=PARAMS):
    # HTD-45H canonical shaft is +Z. Rx(-90°) maps +Z -> +Y.
    return make_htd45h(p).rotate((0, 0, 0), (1, 0, 0), -90)


def make_leg_assembly(p=PARAMS, export_parts=True):
    upper = make_upper_link(p)
    lower = make_lower_link(p).translate((p.leg.upper_link_length, 0, 0))
    foot, sw = make_foot(p)
    foot = foot.translate((p.leg.upper_link_length + p.leg.lower_link_length, 0, 0))

    hip_servo = _servo_axis_y(p)
    knee_servo = _servo_axis_y(p).translate((p.leg.upper_link_length + 28.0, 0, -(p.leg.link_t / 2 + 9.0)))

    parts = {
        "upper_link": upper,
        "lower_link": lower,
        "foot": foot,
        "foot_switch": sw,
        "hip_servo": hip_servo,
        "knee_servo": knee_servo,
    }
    if export_parts:
        names = {
            "upper_link": "leg_upper_link", "lower_link": "leg_lower_link",
            "foot": "leg_foot", "foot_switch": "leg_foot_switch",
            "hip_servo": "leg_hip_servo", "knee_servo": "leg_knee_servo",
        }
        for k, v in names.items():
            export(parts[k], names[k], subdir="leg")
        merged = upper.union(lower).union(foot).union(hip_servo).union(knee_servo)
        export(merged, "leg_master_merged", subdir="leg")
        parts["_merged"] = merged
    return parts


if __name__ == "__main__":
    import build_common as bc
    parts = make_leg_assembly()
    for k, v in parts.items():
        if k.startswith("_"):
            continue
        print(f"{k:14s} size(X,Y,Z)=", [round(r, 1) for r in bc.size_of(v)])


def make_leg_standing(fwd_offset=70.0, p=PARAMS):
    """Build one leg in a standing pose with a level nominal passive foot."""
    import math as _m
    a = p.leg.upper_link_length
    b = p.leg.lower_link_length
    fh = p.leg.foot_height
    D = p.scale.hip_height_nominal

    tx, tz = float(fwd_offset), float(-(D - fh))
    r = _m.hypot(tx, tz)
    r = min(r, a + b - 1e-3)
    r = max(r, abs(a - b) + 1e-3)
    gamma = _m.atan2(tz, tx)
    A = _m.acos(max(-1.0, min(1.0, (a * a + r * r - b * b) / (2 * a * r))))
    d1 = gamma + A
    d2 = _m.atan2(tz - a * _m.sin(d1), tx - a * _m.cos(d1))

    knee = (a * _m.cos(d1), 0.0, a * _m.sin(d1))
    ankle = (knee[0] + b * _m.cos(d2), 0.0, knee[2] + b * _m.sin(d2))

    up_raw = make_upper_link(p)
    lo_raw = make_lower_link(p)
    ft_raw, sw_raw = make_foot(p)

    Ry1 = -_m.degrees(d1)
    up = up_raw.rotate((0, 0, 0), (0, 1, 0), Ry1)
    Ry2 = -_m.degrees(d2)
    lo = lo_raw.rotate((0, 0, 0), (0, 1, 0), Ry2).translate(knee)

    # The ankle is intentionally passive in this nominal standing pose, so keep
    # the sole level with gravity rather than rotating the whole foot with the
    # lower-link axis. The ankle bearing still permits the real assembly to
    # articulate and absorb terrain/load changes.
    ft = ft_raw.translate(ankle)
    sw = sw_raw.translate(ankle)

    hs = _servo_axis_y(p).rotate((0, 0, 0), (0, 1, 0), Ry1)
    ks = _servo_axis_y(p).rotate((0, 0, 0), (0, 1, 0), Ry2).translate(knee)

    return {
        "upper_link": up,
        "lower_link": lo,
        "foot": ft,
        "foot_switch": sw,
        "hip_servo": hs,
        "knee_servo": ks,
        "knee": knee,
        "ankle": ankle,
        "_merged": up.union(lo).union(ft).union(sw).union(hs).union(ks),
    }

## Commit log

2026-08-29 Ori Robot Dog — CAD handoff: Source, Validation, OpenSCAD, CAD_STEP, CAD_STL
    [BOM.csv, arm.forearm.step, arm.forearm.stl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]
2026-08-29 Add Ori CAD engineering rules and definition of done
2026-08-29 Add automated static CAD repository audit
2026-08-29 Add automated CAD validation workflow
2026-08-29 Add CAD repository README and source-of-truth guidance
2026-08-29 Fix CAD validation import paths and arm smoke-build return handling
2026-08-29 Fix leg validator paths and replace hard-coded servo dimensions with master parameters
2026-08-29 Fix load-analysis paths and normalize duplicated torque math
2026-08-29 Fix shaft-analysis paths and remove duplicated torque calculation
2026-08-29 Make wrist validation current, parameter-driven, and honest about powered holding torque
2026-08-29 Fix arm/wrist analysis paths and make torque inputs parameter-driven
2026-08-29 Run the full CAD validation and analysis suite in CI
2026-08-29 Document CAD/software architecture blockers and unresolved engineering state
2026-08-29 Make software joint map match current CAD implementation and flag unimplemented hip-yaw
2026-08-29 Make CAD repository README reflect current implementation and validation state
2026-08-29 Fix CAD repository root resolution and canonicalize STEP/STL exports
2026-08-29 Add one-command CAD validation entry point
2026-08-29 Align primary README with current CAD implementation and engineering state
2026-08-29 Simplify CI to use the single full CAD validation entry point
2026-08-29 Rewrite mechanical handoff to match current CAD and separate implemented state from target architecture
2026-08-29 Align BOM with current 16-DOF implementation and mark hip-yaw as target only
    [BOM.csv]
2026-08-29 Correct wrist grip gear/servo axis alignment and clean up gripper coordinate frame
2026-08-29 Strengthen CAD repository audit around source roots and implementation-state consistency
2026-08-29 Rewrite wrist analysis to match current arm CAD and remove stale conflicting architectures
2026-08-29 Correct wrist analysis log units and align it with current gripper architecture
2026-08-29 Update printable-splits documentation to current torso size and current CAD architecture
2026-08-29 Update documentation index to current CAD layout and implementation state
2026-08-29 Replace stale handoff delta with current repository cleanup and engineering state
2026-08-29 Tighten static CAD audit checks and correct joint-map axis validation
2026-08-29 Correct HTD-45H Y-axis installation transform in master leg CAD
    [master_leg.py]
2026-08-29 Correct remaining arm servo axis transforms against canonical HTD-45H frame
2026-08-29 Correct head pitch servo axis and align source with current joint-map conventions
2026-08-29 Rewrite verification status to match current CAD implementation and honest evidence levels
2026-08-29 Fix leg validator for installed HTD-45H axes
2026-08-29 Add Ori CAD Engineer GitHub custom agent
2026-08-29 Strengthen Ori engineering rules and arm reinforcement requirements
2026-08-30 Fix standing pose so passive feet remain level
    [master_leg.py]
2026-08-30 Fix handoff export to use tracked shaft deliverables
